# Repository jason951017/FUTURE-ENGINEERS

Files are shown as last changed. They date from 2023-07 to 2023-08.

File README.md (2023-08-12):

# 機器人比賽工程日誌 - 視覺感應避障電動車

## 簡介

歡迎來到我們的機器人比賽工程日誌！我們準備參加一場視覺感應避障電動車的比賽。我們的目標是製作一台自動導航並能根據視覺感應器來避免障礙物的電動車。這份日誌將記錄我們在組裝和優化車輛過程中的進展、挑戰和解決方案。
# 壹.移動性管理

## 一. 馬達選擇

在初期階段，我們仔細考慮了不同的馬達選項，最終選擇了更小的N20馬達，而不是EV3樂高馬達。這個選擇不僅讓我們的車輛更加緊湊，還能提供更好的靈活性，以實現有效的閃避障礙物。

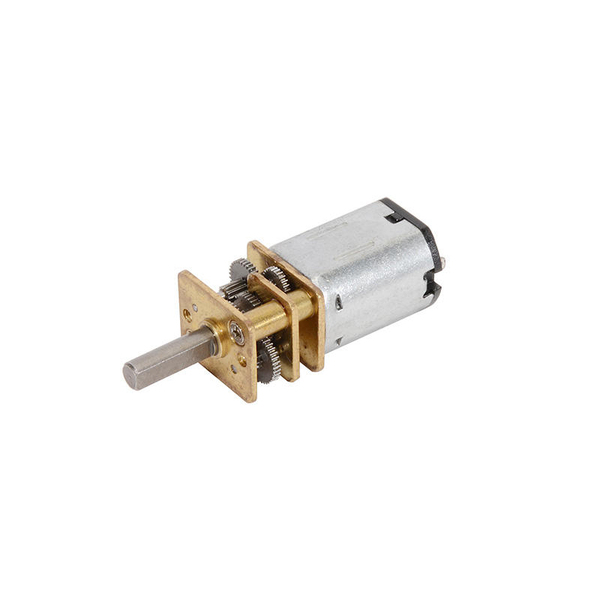
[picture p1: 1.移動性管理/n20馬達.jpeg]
N20馬達

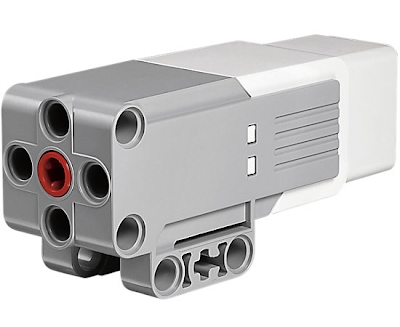
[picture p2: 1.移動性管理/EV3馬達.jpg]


## 二. 底盤設計

為了確保車輛的機動性，我們決定使用3D列印技術設計一個自定義的底盤，同時解決了遙控車底盤迴轉半徑過大的問題。這個決定將讓我們製作一個專為我們需求度身訂造的底盤，以提高整體性能。

### 遙控車迴轉半徑：

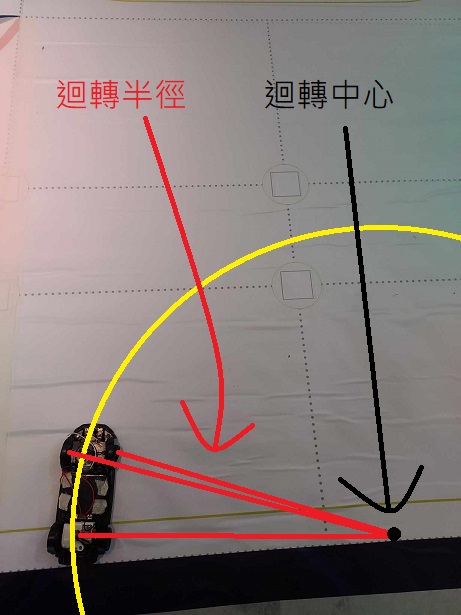
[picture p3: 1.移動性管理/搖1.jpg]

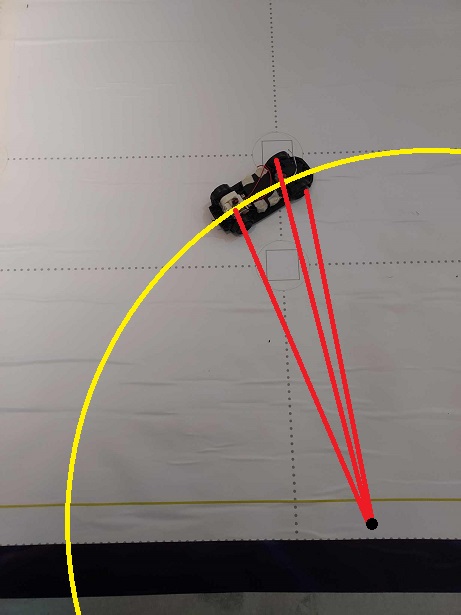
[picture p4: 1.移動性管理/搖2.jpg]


### 3D列印車迴轉半徑：

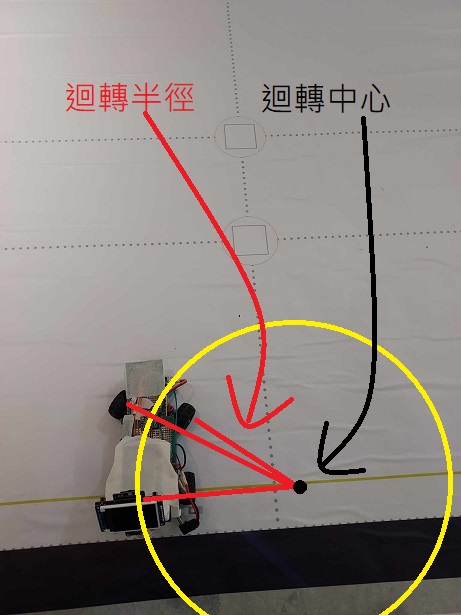
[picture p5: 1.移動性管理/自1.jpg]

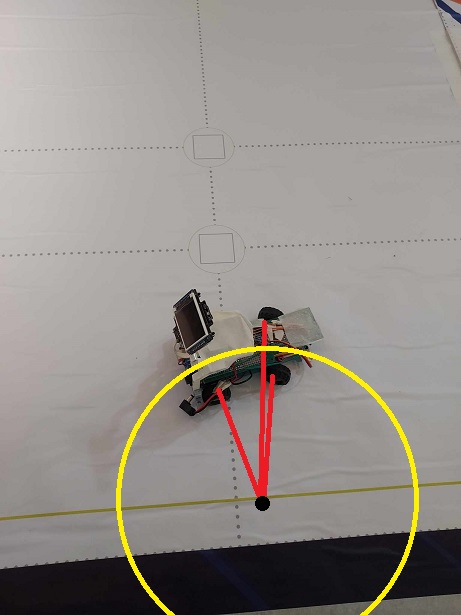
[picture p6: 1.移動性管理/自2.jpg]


由上圖比對發現遙控車底盤迴轉半徑過大，可能影響閃避交通號誌，所以最終選擇用3D列印底盤車解決此問題。

## 三. 3D列印齒輪

為了確保馬達和樂高零件的齒輪相匹配，我們自行使用3D列印技術設計了合適的齒輪。這將實現在車輛內部有效地傳遞動力。

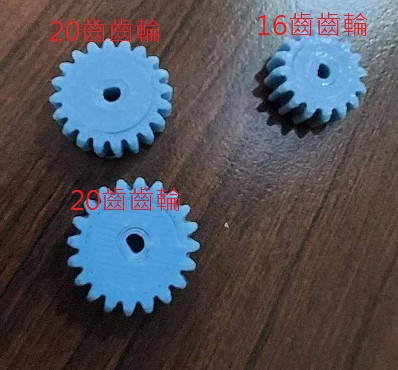
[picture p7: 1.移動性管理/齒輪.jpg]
自製齒輪


## 四. 馬達轉速

我們進行了馬達轉速的測試，以瞭解其性能特點。以下是馬達在不同電壓下的轉速結果圖：

紅色框選部分為我們挑選馬達的數據

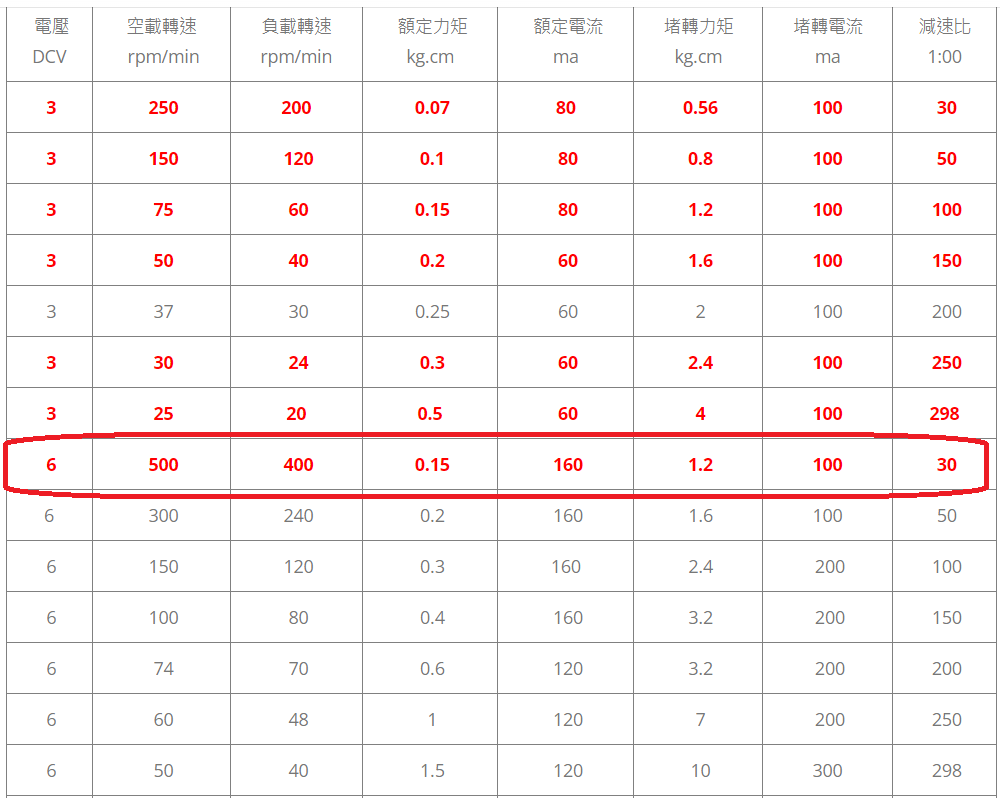
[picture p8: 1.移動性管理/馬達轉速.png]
馬達轉速圖


## 五. 差速器齒輪比

為了實現差速操控，我們計算並設計了適合後輪的差速器齒輪比大約等於400*(16-24)=266.667

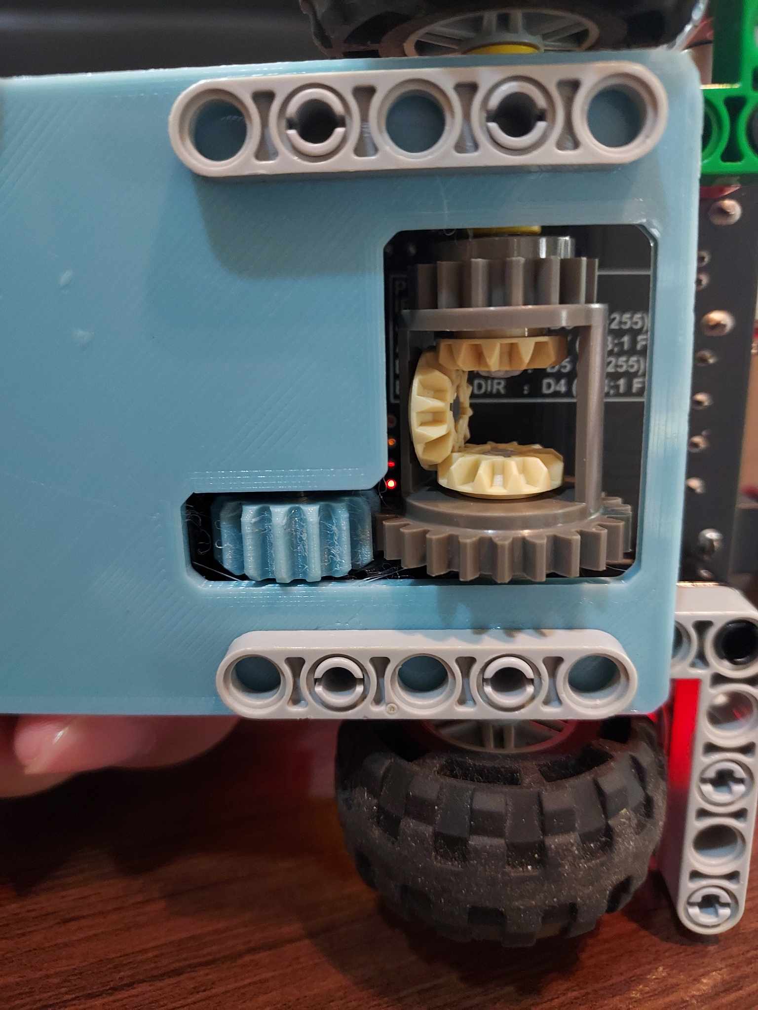
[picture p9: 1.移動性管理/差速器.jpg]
差速器齒輪


## 六. 裝配說明

以下是包括底盤和框架的裝配指南和零件實裝圖：

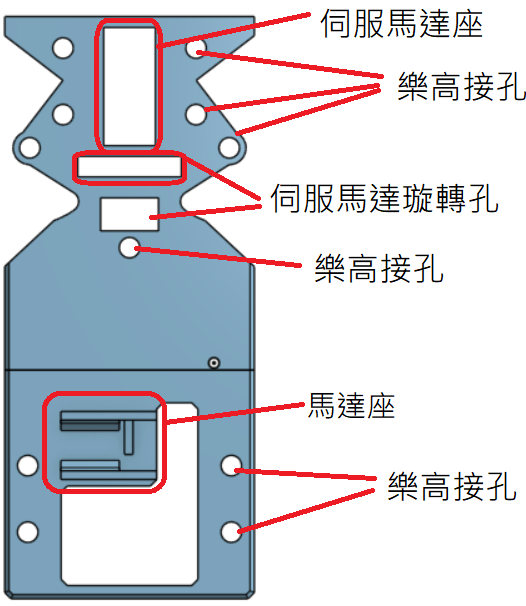
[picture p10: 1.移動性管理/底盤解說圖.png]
裝配說明

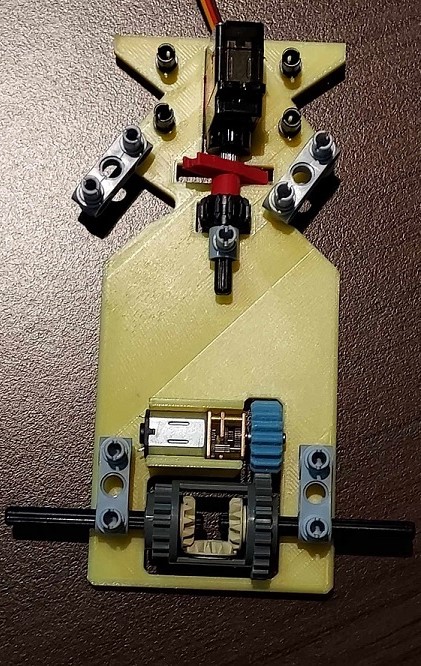
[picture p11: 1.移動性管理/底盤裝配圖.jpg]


## 七. 3D元件三視圖及stl圖檔

整個車輛元件的三視圖：

### 頂視圖：

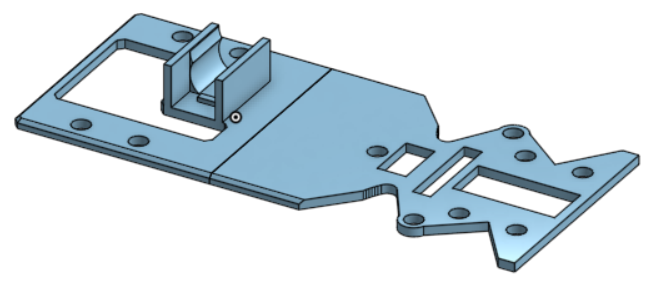
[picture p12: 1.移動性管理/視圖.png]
頂視圖


### 正視圖：

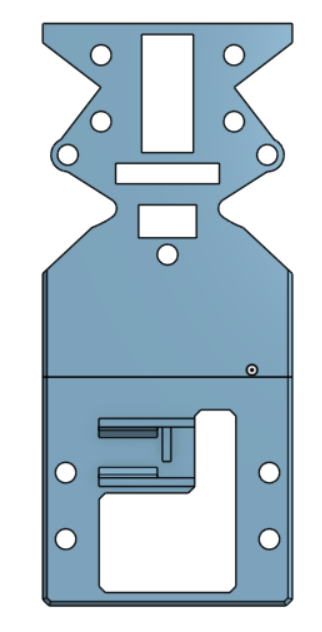
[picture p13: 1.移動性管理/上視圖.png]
正視圖


### 側視圖：

側視圖

### stl圖檔：

[stl圖檔](1.移動性管理/FE全.stl)

# 貳.電源和感測器管理

## 一. nicjoy14500金屬鋰電池

這是車輛的動力來源，提供電力給主控板、馬達以及其他電子裝置。選用金屬鋰電池而不是模型電池是因為nicjoy金屬鋰電池體積更小，更方便縮小車輛體積及配重。
一節電池電壓為3.7 ~ 4.2伏特，穩態電壓3.7伏特，我們使用兩節電池實際電壓為7.4 ~ 8.4伏特，電壓輸入到主控版後會經過穩壓晶片將電壓穩壓到5伏特和3.3伏特再分配到主控板和其他感應器。

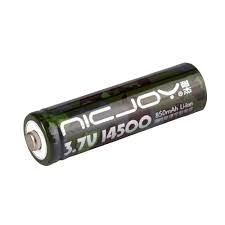
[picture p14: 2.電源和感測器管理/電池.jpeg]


## 二.主控板

Krduino主控板：這是整個車輛的主要控制板，負責管理和協調其他零件的運作。主控板通過程式碼控制各個感測器和執行器的動作，實現車輛的自主運行和障礙物避免功能。

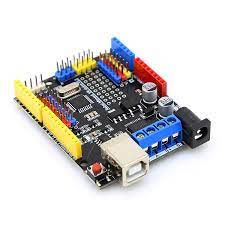
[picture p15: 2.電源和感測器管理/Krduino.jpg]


  #### 二-1 馬達驅動馬達驅動版tb6612

   tb6612是用於控制電動車的馬達。在車輛中，tb6612驅動晶片負責控制馬達的速度和方向，進而實現車輛的運動和轉向控制。已內建整合於主控板中。

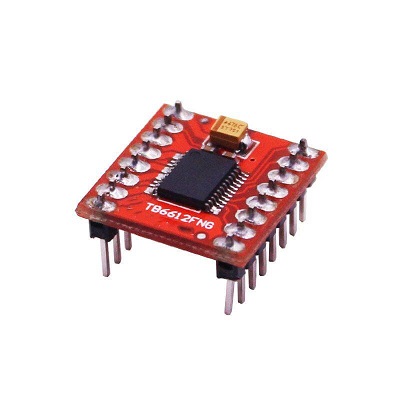
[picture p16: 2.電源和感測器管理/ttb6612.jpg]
   

## 三.陀螺儀mpu6050

這是一個慣性感測器，能夠檢測車輛的傾斜和轉動。通過i2c通訊讀取陀螺儀數據，主控板可以判斷車輛的傾斜狀態，從而實現平穩的移動和轉向。

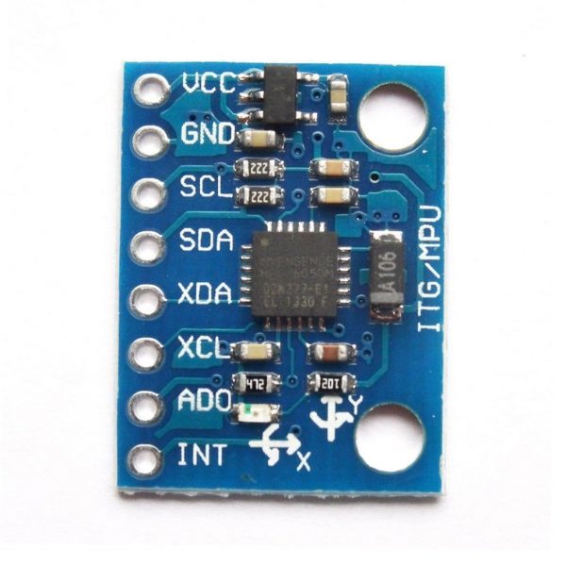
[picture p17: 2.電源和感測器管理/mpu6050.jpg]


## 四.顏色感應器tcs34725

這個感應器可以識別周圍環境的顏色。在比賽中，我們通過i2c通訊讀取感應器數據來辨別地面狀態，以便車輛做出適當的反應和閃避動作。

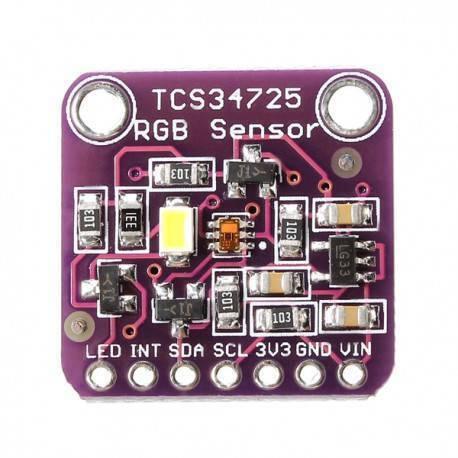
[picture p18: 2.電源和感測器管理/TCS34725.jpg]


## 五.攝影機esp32cam

攝影機是視覺感應器的一種，它可以拍攝周圍的場景。透過攝影機的影像處理，車輛可以識別前方的障礙物或路徑，並進行適應性的運動控制。

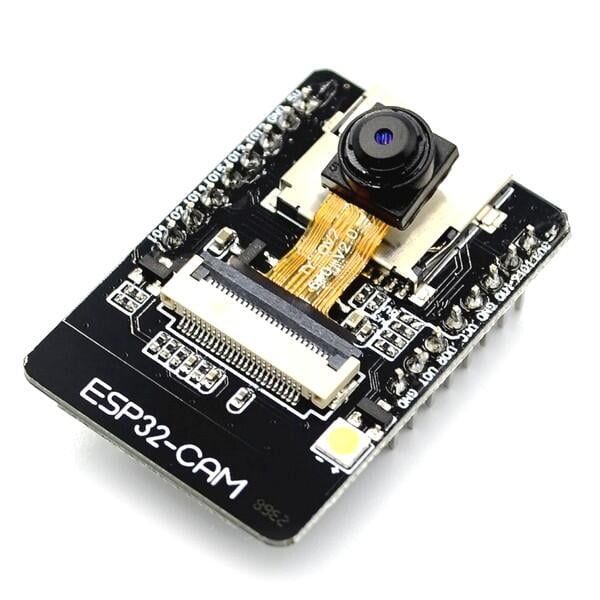
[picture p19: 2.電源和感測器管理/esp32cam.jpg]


## 六.超音波hc-sr04

這個超音波感測器可以測量車輛與前方障礙物之間的距離。藉由這個數據，車輛可以避免與障礙物碰撞，實現安全的運行。

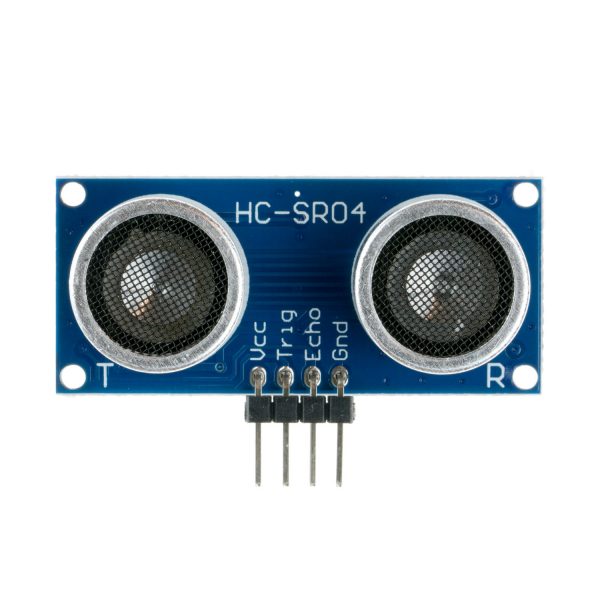
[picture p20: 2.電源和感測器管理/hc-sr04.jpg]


## 七.按鈕

按鈕是一種輸入裝置，可以用來控制車輛的啟動、停止或其他功能。在比賽中，我們將按鈕用來操控車輛的啟動。

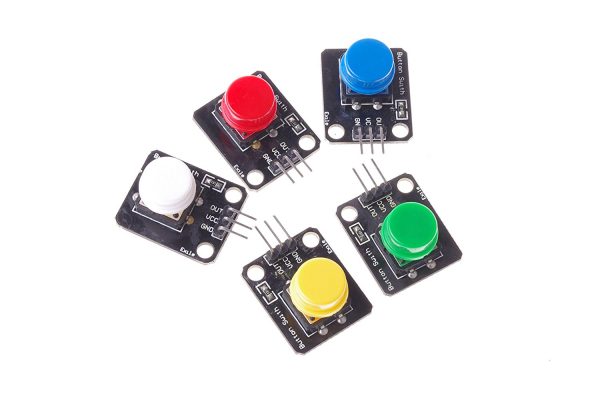
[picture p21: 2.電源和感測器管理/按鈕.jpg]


## 八.三色指示燈

這些燈光裝置用來顯示車輛的狀態或提供提示信息。例如，可以利用指示燈顯示車輛是否處於運行中，或者是否偵測到了障礙物，若程式有誤還能方便及時更正程式。



# 參.障礙管理

以下是我們車輛的程式碼

```
#include "init.h"

int ya = 0, yb = 1, cmin, cmax;

void setup() {
  // 初始化感應器
  FeInit();
  getDis();
  delayMicroseconds(250);
  static int ldis, fix5 = 0, lastColor = 0, turnback = 0;
  while (true) {
    // 沿陀螺儀相對零度角前進並進行避障
    rygSet(0, 0, 0);
    if ((CameraGet(3) > 15) || (CameraGet(7) > 15)) {
      caturn_turn();
      if (CameraGet(3) > 15) fix5 = -20;
      if (CameraGet(7) > 15) fix5 = 20;
    } else {
      setTurn(getRelGyro(0) * 1.2);
    }
    motorSpd(250);
    // 利用光源感應器分辨地面上藍橘線得知行進方向為順時針或逆時針
    int color = getTcs();
    if (color > 0 && color < 40) {
      ya = 1;
      cmin = 0;
      cmax = 40;
      break;
    }
    if (color > 200 && color < 240) {
      ya = -1;
      cmin = 200;
      cmax = 240;
      break;
    }
  }
}

// 20,220
void loop() {
  rygSet(0, 0, 0);
  static byte b = 0, c = 0;
  static int ldis, fix5 = 0, lastColor = 0;
  static uint32_t a = 0, timer = 0, back = 0, straightTime = 0;
  motorSpd(250);
  // 記數進行8次
  for (int r = 0; r < 8; r++) {
    // 前進直到偵測到地圖上藍橘線
    while (getTcs() < cmin || getTcs() > cmax) {
      // 沿陀螺儀相對零度角前進並進行避障
      if ((CameraGet(3) > 15) || (CameraGet(7) > 15)) {
        caturn_turn();
      } else {
        setTurn(getRelGyro(a + fix5) * 1.2);
      }
      if (r == 4) {
        if (CameraGet(3) > 15) {
          // 將相對角目標調整90度
          a += ya * 90;
        }
        //*****************************************************************************
        // 轉向直到與目標角度相差小於10度
        while (getRelGyro(a) > 10 || getRelGyro(a) < -10) {
          motorSpd(250);
          // 在觀測到障礙後進行避障
          if ((CameraGet(3) > 15) || (CameraGet(7) > 15)) {
            caturn_turn();
          }
          setTurn(getRelGyro(a) * 1.2);
        }
      }
    }
  }
  //*********************************************************************************************
  straightTime = millis() + 700;
  if (lastColor == -1) {
    rygSet(0, 0, 0);
    // 前進0.7秒並在途中進行避障
    while (millis() < straightTime) {
      motorSpd(250);
      caturn_turn();
    }
    //*************************************************************************************************
    // 改變地面上藍橘線目標色相值
    if (ya == 1) {
      cmin = 200;
      cmax = 240;
    } else {
      cmin = 0;
      cmax = 40;
    }
    // 沿相對角180度後退
    straightTime = millis() + 1800;
    while (millis() < straightTime) {
      motorSpd(-250);
      setTurn(getRelGyro(a) * (-1));
    }
    // 轉向直到與目標角相差小於10度
    a += ya * 90;
    while (getRelGyro(a) > 10 || getRelGyro(a) < -10) {
      motorSpd(250);
      setTurn(getRelGyro(a) * 1.2);
    }
  }
  //****************************************************************************
  // 前進1秒並在途中進行避障
  straightTime = millis() + 1000;
  while (millis() < straightTime) {
    setTurn(getRelGyro(a) * 1.2);
    caturn_turn();
  }
  //****************************************************************************
  // 記數3+(是否往反方向)次
  for (int r = 0; r < (3 + (lastColor > 0)); r++) {
    // 前進直到偵測到地圖上藍橘線
    while (getTcs() < cmin || getTcs() > cmax) {
      // 沿陀螺儀相對零度角前進並進行避障
      if ((CameraGet(3) > 15) || (CameraGet(7) > 15)) {
        caturn_turn();
      } else {
        setTurn(getRelGyro(a + fix5) * 1.2);
      }
    }
    //******************************************************************************************
    // 將目標角調整90度
    a += ya * 90 * lastColor;
    //******************************************************************************************
    // 轉向直到與目標角度相差小於10度
    while (getRelGyro(a) > 10 || getRelGyro(a) < -10) {
      motorSpd(250);
      // 在觀測到障礙後進行避障
      if ((CameraGet(3) > 15) || (CameraGet(7) > 15)) {
        caturn_turn();
      }
      setTurn(getRelGyro(a) * 1.2);
    }
  }
  //*******************************************************************************************
  // 前進0.8秒後停止
  straightTime = millis() + 800;
  while (millis() < straightTime) {
    motorSpd(250);
    caturn_turn();
  }
  while (1) {
    motorSpd(0);
  }
}

```

# 肆.圖片-團隊以及汽車

## 一.團隊照片

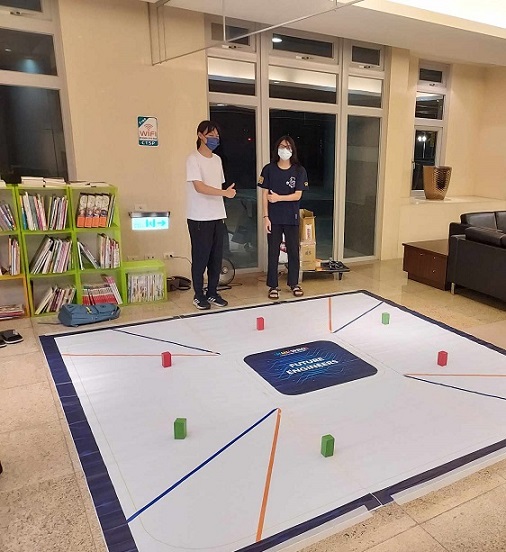
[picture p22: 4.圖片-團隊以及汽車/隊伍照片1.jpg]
隊伍照片

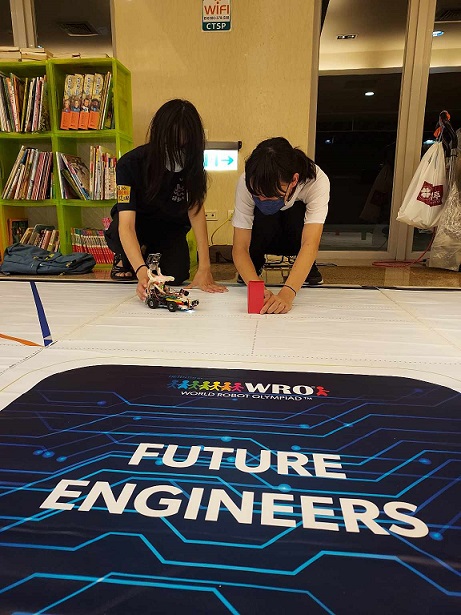
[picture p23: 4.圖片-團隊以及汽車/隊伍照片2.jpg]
隊伍照片

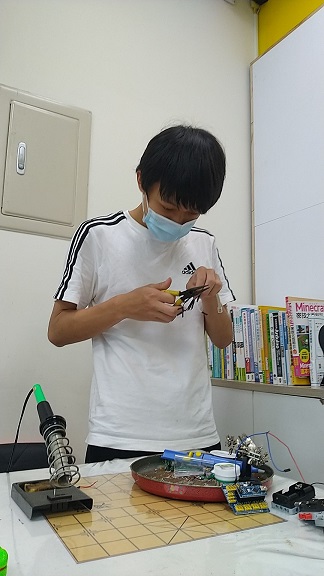
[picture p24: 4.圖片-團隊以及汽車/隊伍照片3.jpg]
隊伍照片

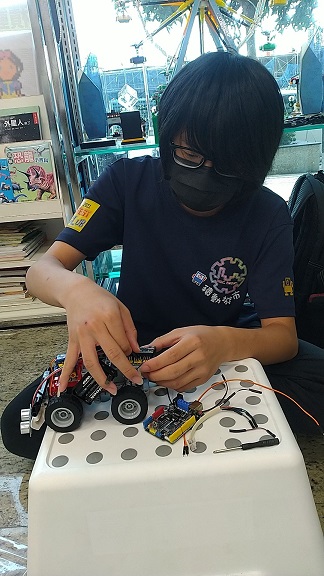
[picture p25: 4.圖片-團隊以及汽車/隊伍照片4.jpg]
隊伍照片

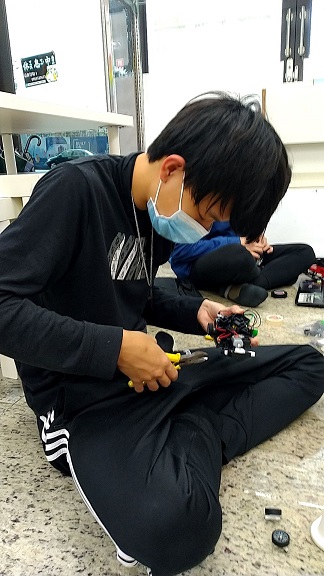
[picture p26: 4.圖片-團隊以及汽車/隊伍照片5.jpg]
隊伍照片

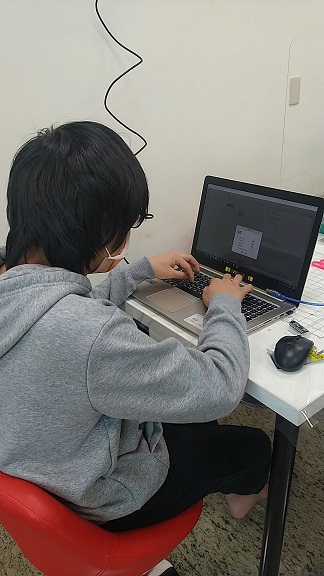
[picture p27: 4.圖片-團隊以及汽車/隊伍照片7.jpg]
隊伍照片

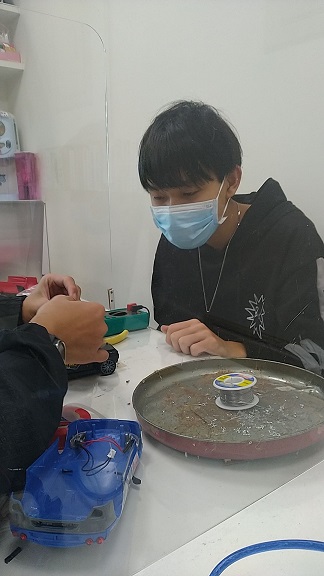
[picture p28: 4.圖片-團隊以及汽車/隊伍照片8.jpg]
隊伍照片

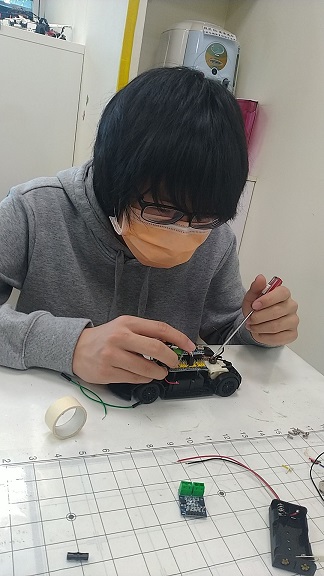
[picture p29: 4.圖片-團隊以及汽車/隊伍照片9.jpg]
隊伍照片

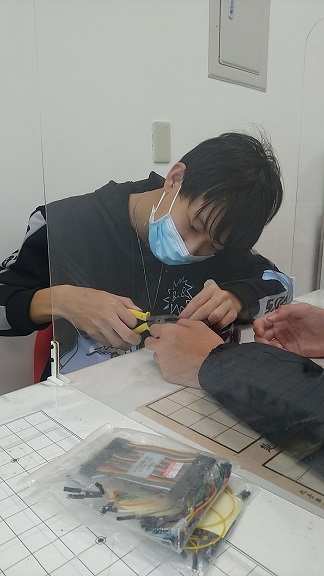
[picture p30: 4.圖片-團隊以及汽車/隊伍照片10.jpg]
隊伍照片

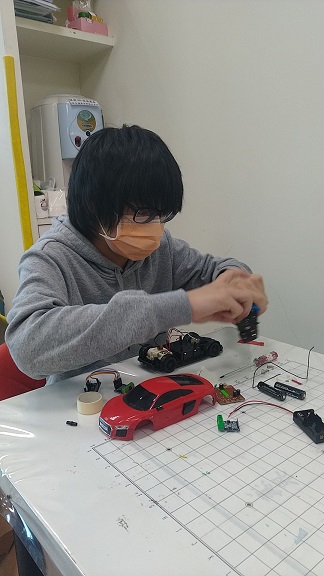
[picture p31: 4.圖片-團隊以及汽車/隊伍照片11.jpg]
隊伍照片

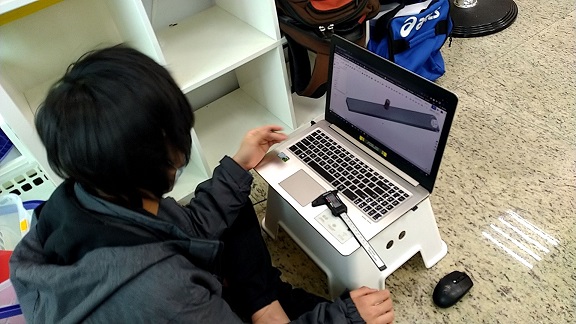
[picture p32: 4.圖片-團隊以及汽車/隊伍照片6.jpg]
隊伍照片


## 二.車輛照片

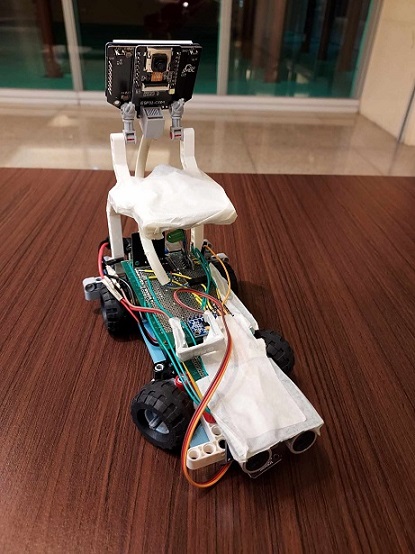
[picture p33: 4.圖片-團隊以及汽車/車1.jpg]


## 側視圖:

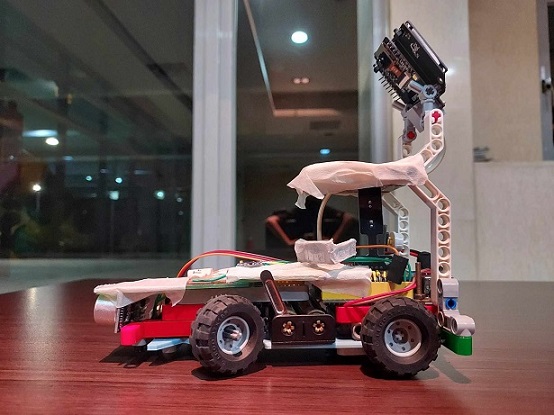
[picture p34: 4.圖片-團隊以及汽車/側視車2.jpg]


## 上視圖:

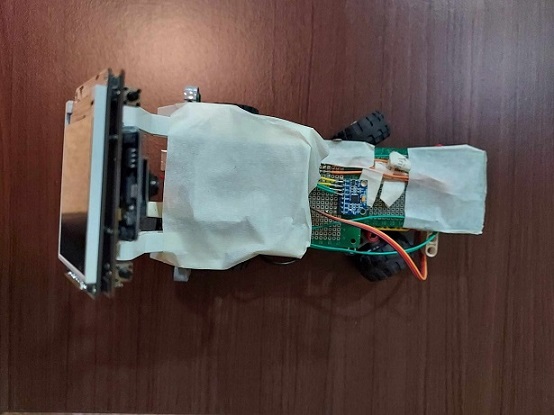
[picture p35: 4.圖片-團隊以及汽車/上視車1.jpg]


# 伍.完整的影片

## 影片連結:

### future engineer-開放挑戰
https://www.youtube.com/watch?v=iF_I76seYgM

### 障礙物挑戰-有迴轉
https://www.youtube.com/watch?v=U3aca9URPHw

### 障礙物挑戰-無迴轉
https://www.youtube.com/watch?v=v_WyIpfcISQ

# 陸.GitHub使用

## GitHub使用心得
我是一個幾乎不會打報告、上網查資料的人，但這次參加Future Engineer比賽之後，我開始使用GitHub來紀錄我的比賽實驗過程。這是一個讓我難以置信的改變，讓我在技術和協作方面得到了巨大的成長。一開始，我對於GitHub毫無了解，但是在比賽中，我不得不學會如何使用它，因為它是我們整個比賽的過程記錄中心。這次Future Engineer比賽讓我成為了一個會使用GitHub、上網查資料的人。GitHub幫助我更好地組織我的工作、與團隊合作、學習他人的經驗，並且使我對於技術更加自信。我相信這個工具將會伴隨著我在未來的學習和職業生涯中，繼續扮演著重要的角色。

# 柒.工程因素及技術條件
這一個章節要呈現我們自行設計和製造車輛和部件，以及整合現成的電子零件。

## 一.現成電子零件

### 1.nicjoy14500金屬鋰電池

這是車輛的動力來源，提供電力給主控板、馬達以及其他電子裝置。選用金屬鋰電池而不是模型電池是因為nicjoy金屬鋰電池體積更小，更方便縮小車輛體積及配重。
一節電池電壓為3.7 ~ 4.2伏特，穩態電壓3.7伏特，我們使用兩節電池實際電壓為7.4 ~ 8.4伏特，電壓輸入到主控版後會經過穩壓晶片將電壓穩壓到5伏特和3.3伏特再分配到主控板和其他感應器。



### 2.主控板

Krduino主控板：這是整個車輛的主要控制板，負責管理和協調其他零件的運作。主控板通過程式碼控制各個感測器和執行器的動作，實現車輛的自主運行和障礙物避免功能。



   2-1 馬達驅動馬達驅動版tb6612

   tb6612是用於控制電動車的馬達。在車輛中，tb6612驅動晶片負責控制馬達的速度和方向，進而實現車輛的運動和轉向控制。已內建整合於主控板中。

   

### 2.陀螺儀mpu6050

這是一個慣性感測器，能夠檢測車輛的傾斜和轉動。通過i2c通訊讀取陀螺儀數據，主控板可以判斷車輛的傾斜狀態，從而實現平穩的移動和轉向。



### 3.顏色感應器tcs34725

這個感應器可以識別周圍環境的顏色。在比賽中，我們通過i2c通訊讀取感應器數據來辨別地面狀態，以便車輛做出適當的反應和閃避動作。



### 4.攝影機esp32cam

攝影機是視覺感應器的一種，它可以拍攝周圍的場景。透過攝影機的影像處理，車輛可以識別前方的障礙物或路徑，並進行適應性的運動控制。



### 5.超音波hc-sr04

這個超音波感測器可以測量車輛與前方障礙物之間的距離。藉由這個數據，車輛可以避免與障礙物碰撞，實現安全的運行。



### 6.按鈕

按鈕是一種輸入裝置，可以用來控制車輛的啟動、停止或其他功能。在比賽中，我們將按鈕用來操控車輛的啟動。



### 7.三色指示燈

這些燈光裝置用來顯示車輛的狀態或提供提示信息。例如，可以利用指示燈顯示車輛是否處於運行中，或者是否偵測到了障礙物，若程式有誤還能方便及時更正程式。



## 二. 介紹初代汽車和改進後的車輛

### 1.初代汽車照片
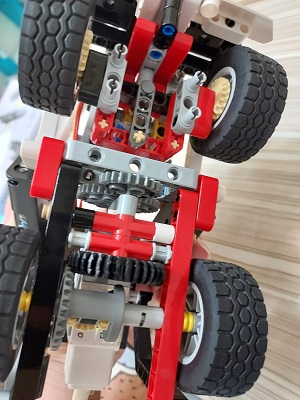
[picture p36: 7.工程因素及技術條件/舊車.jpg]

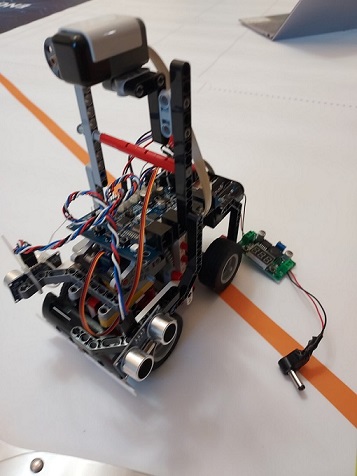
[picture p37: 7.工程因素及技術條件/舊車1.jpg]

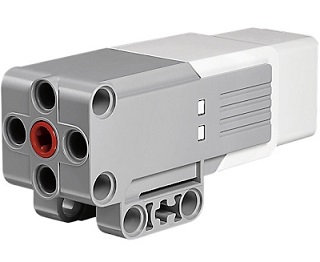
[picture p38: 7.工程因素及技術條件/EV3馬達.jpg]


這是改裝前的初代汽車底盤照片，使用的是EV3馬達，整輛車幾乎都是用樂高零件組成，看起來是一輛體積相對稍大的車輛。

### 2.改進後的車輛


這是改進後的車輛照片，我們改裝了底盤和馬達，加入了新的零件和設備，使車輛體積縮小的同時擁有了更多功能。

## 三. 焊接電路板和電路板功能
我們加裝這塊電路板是因為之前沒電路板的機構容易因使用時常增加，導致杜邦線鬆，動進而引發接觸不良的問題，所以自己到電子材料行買了兩塊焊接板自己製作一塊電路板。

### 1.電路板接線設計圖
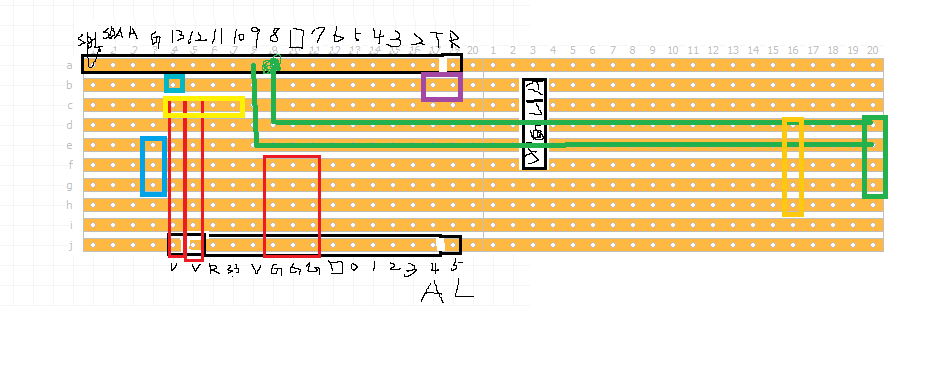
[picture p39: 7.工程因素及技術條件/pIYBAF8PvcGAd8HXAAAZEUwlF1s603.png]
電路板接線設計圖


這是我們為電路板進行的接線設計圖，確保電路板的連接正確，以實現各個零件間的順利通訊。

### 2.電路板焊接過程
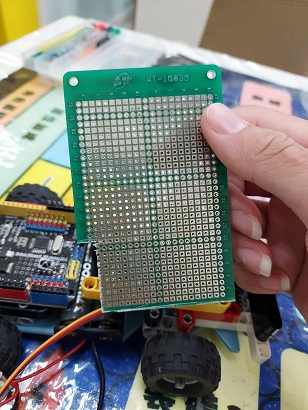
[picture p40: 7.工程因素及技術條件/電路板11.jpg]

電路板
電路板

這是電路板焊接過程的照片，我們仔細地將各個電子元件焊接在電路板上，確保連接可靠且無誤。

### 3.電路板完成圖
電路板完成圖
電路板完成圖

### 4.電路板突發狀況

由於鄰近比賽，車輛上的krduino主控板晶片因操作不當導致短路燒壞控板，所以主控板臨時改成arduino UNO板。

由於krduino板和UNO板有一些腳位差異，所以將電路板的一些接角重新焊接。
出事

這是已完成且裝配好的電路板照片，所有電子元件都已經焊接完成並接線正確。這個電路板是整個車輛的核心，它負責接收和處理各個感測器的數據，並控制馬達和其他執行器的動作，以實現車輛的自主運行和視覺感應閃避障礙物功能。
## 四. 底盤設計

為了確保車輛的機動性，我們決定使用3D列印技術設計一個自定義的底盤，同時解決了遙控車底盤迴轉半徑過大的問題。這個決定將讓我們製作一個專為我們需求度身訂造的底盤，以提高整體性能。

### 1. 遙控車迴轉半徑：

遙控車
遙控車

### 3D列印車迴轉半徑：

3D車
3D車

由上圖比對發現遙控車底盤迴轉半徑過大，可能影響閃避交通號誌，所以最終選擇用3D列印底盤車解決此問題。

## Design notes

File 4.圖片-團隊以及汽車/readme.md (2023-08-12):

## 1.團隊照片

隊伍照片
隊伍照片
隊伍照片
隊伍照片
隊伍照片
隊伍照片
隊伍照片
隊伍照片
隊伍照片
隊伍照片
隊伍照片

## 2.車輛照片



# 側視圖:



# 上視圖:



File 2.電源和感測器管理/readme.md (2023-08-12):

## 一. nicjoy14500金屬鋰電池

這是車輛的動力來源，提供電力給主控板、馬達以及其他電子裝置。選用金屬鋰電池而不是模型電池是因為nicjoy金屬鋰電池體積更小，更方便縮小車輛體積及配重。
一節電池電壓為3.7 ~ 4.2伏特，穩態電壓3.7伏特，我們使用兩節電池實際電壓為7.4 ~ 8.4伏特，電壓輸入到主控版後會經過穩壓晶片將電壓穩壓到5伏特和3.3伏特再分配到主控板和其他感應器。



## 二.主控板

Krduino主控板：這是整個車輛的主要控制板，負責管理和協調其他零件的運作。主控板通過程式碼控制各個感測器和執行器的動作，實現車輛的自主運行和障礙物避免功能。



   二-1 馬達驅動馬達驅動版tb6612

   tb6612是用於控制電動車的馬達。在車輛中，tb6612驅動晶片負責控制馬達的速度和方向，進而實現車輛的運動和轉向控制。已內建整合於主控板中。

   

## 三.陀螺儀mpu6050

這是一個慣性感測器，能夠檢測車輛的傾斜和轉動。通過i2c通訊讀取陀螺儀數據，主控板可以判斷車輛的傾斜狀態，從而實現平穩的移動和轉向。



## 四.顏色感應器tcs34725

這個感應器可以識別周圍環境的顏色。在比賽中，我們通過i2c通訊讀取感應器數據來辨別地面狀態，以便車輛做出適當的反應和閃避動作。



## 五.攝影機esp32cam

攝影機是視覺感應器的一種，它可以拍攝周圍的場景。透過攝影機的影像處理，車輛可以識別前方的障礙物或路徑，並進行適應性的運動控制。



## 六.超音波hc-sr04

這個超音波感測器可以測量車輛與前方障礙物之間的距離。藉由這個數據，車輛可以避免與障礙物碰撞，實現安全的運行。



## 七.按鈕

按鈕是一種輸入裝置，可以用來控制車輛的啟動、停止或其他功能。在比賽中，我們將按鈕用來操控車輛的啟動。



## 八.三色指示燈

這些燈光裝置用來顯示車輛的狀態或提供提示信息。例如，可以利用指示燈顯示車輛是否處於運行中，或者是否偵測到了障礙物，若程式有誤還能方便及時更正程式。



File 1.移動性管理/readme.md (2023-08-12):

# 機器人比賽工程日誌 - 視覺感應避障電動車

## 簡介

歡迎來到我們的機器人比賽工程日誌！我們準備參加一場視覺感應避障電動車的比賽。我們的目標是製作一台自動導航並能根據視覺感應器來避免障礙物的電動車。這份日誌將記錄我們在組裝和優化車輛過程中的進展、挑戰和解決方案。

## 一. 馬達選擇

在初期階段，我們仔細考慮了不同的馬達選項，最終選擇了更小的N20馬達，而不是EV3樂高馬達。這個選擇不僅讓我們的車輛更加緊湊，還能提供更好的靈活性，以實現有效的閃避障礙物。

N20馬達
EV3馬達

## 二. 底盤設計

為了確保車輛的機動性，我們決定使用3D列印技術設計一個自定義的底盤，同時解決了遙控車底盤迴轉半徑過大的問題。這個決定將讓我們製作一個專為我們需求度身訂造的底盤，以提高整體性能。

### 遙控車迴轉半徑：

遙控車
遙控車

### 3D列印車迴轉半徑：

3D車
3D車

由上圖比對發現遙控車底盤迴轉半徑過大，可能影響閃避交通號誌，所以最終選擇用3D列印底盤車解決此問題。

## 三. 3D列印齒輪

為了確保馬達和樂高零件的齒輪相匹配，我們自行使用3D列印技術設計了合適的齒輪。這將實現在車輛內部有效地傳遞動力。

自製齒輪

## 四. 馬達轉速

我們進行了馬達轉速的測試，以瞭解其性能特點。以下是馬達在不同電壓下的轉速結果圖：

紅色框選部分為我們挑選馬達的數據

馬達轉速圖

## 五. 差速器齒輪比

為了實現差速操控，我們計算並設計了適合後輪的差速器齒輪比大約等於400*(16-24)=266.667

差速器齒輪

## 六. 裝配說明

以下是包括底盤和框架的裝配指南和零件實裝圖：

裝配說明


## 七. 3D元件三視圖及stl圖檔

整個車輛元件的三視圖：

### 頂視圖：

頂視圖

### 正視圖：

正視圖

### 側視圖：

側視圖

### stl圖檔：

[stl圖檔](FE全.stl)

## 總結

作為準備參加機器人比賽的參賽選手，我們致力於從理論到實踐，不斷優化我們的電動車項目。在視覺感應避障電動車的構建過程中，我們將著重於馬達、齒輪、感應器和差速器的組裝與優化。這個日誌將是我們工程進度的詳盡紀錄，同時也會反映出我們團隊的合作精神和創新思維。讓我們攜手合作，打造一輛優秀的視覺感應避障電動車。

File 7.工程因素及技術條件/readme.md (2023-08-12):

# 柒.工程因素及技術條件
這一個章節要呈現我們自行設計和製造車輛和部件，以及整合現成的電子零件。

## 一.現成電子零件

1.nicjoy14500金屬鋰電池

這是車輛的動力來源，提供電力給主控板、馬達以及其他電子裝置。選用金屬鋰電池而不是模型電池是因為nicjoy金屬鋰電池體積更小，更方便縮小車輛體積及配重。
一節電池電壓為3.7 ~ 4.2伏特，穩態電壓3.7伏特，我們使用兩節電池實際電壓為7.4 ~ 8.4伏特，電壓輸入到主控版後會經過穩壓晶片將電壓穩壓到5伏特和3.3伏特再分配到主控板和其他感應器。



2.主控板

Krduino主控板：這是整個車輛的主要控制板，負責管理和協調其他零件的運作。主控板通過程式碼控制各個感測器和執行器的動作，實現車輛的自主運行和障礙物避免功能。



   2-1 馬達驅動馬達驅動版tb6612

   tb6612是用於控制電動車的馬達。在車輛中，tb6612驅動晶片負責控制馬達的速度和方向，進而實現車輛的運動和轉向控制。已內建整合於主控板中。

   

2.陀螺儀mpu6050

這是一個慣性感測器，能夠檢測車輛的傾斜和轉動。通過i2c通訊讀取陀螺儀數據，主控板可以判斷車輛的傾斜狀態，從而實現平穩的移動和轉向。



3.顏色感應器tcs34725

這個感應器可以識別周圍環境的顏色。在比賽中，我們通過i2c通訊讀取感應器數據來辨別地面狀態，以便車輛做出適當的反應和閃避動作。



4.攝影機esp32cam

攝影機是視覺感應器的一種，它可以拍攝周圍的場景。透過攝影機的影像處理，車輛可以識別前方的障礙物或路徑，並進行適應性的運動控制。



5.超音波hc-sr04

這個超音波感測器可以測量車輛與前方障礙物之間的距離。藉由這個數據，車輛可以避免與障礙物碰撞，實現安全的運行。



6.按鈕

按鈕是一種輸入裝置，可以用來控制車輛的啟動、停止或其他功能。在比賽中，我們將按鈕用來操控車輛的啟動。



7.三色指示燈

這些燈光裝置用來顯示車輛的狀態或提供提示信息。例如，可以利用指示燈顯示車輛是否處於運行中，或者是否偵測到了障礙物，若程式有誤還能方便及時更正程式。



## 二. 介紹初代汽車和改進後的車輛

### 1.初代汽車照片
舊車
舊車
EV3馬達

這是改裝前的初代汽車底盤照片，使用的是EV3馬達，整輛車幾乎都是用樂高零件組成，看起來是一輛體積相對稍大的車輛。

### 2.改進後的車輛


這是改進後的車輛照片，我們改裝了底盤和馬達，加入了新的零件和設備，使車輛體積縮小的同時擁有了更多功能。

## 三. 焊接電路板和電路板功能
我們加裝這塊電路板是因為之前沒電路板的機構容易因使用時常增加，導致杜邦線鬆，動進而引發接觸不良的問題，所以自己到電子材料行買了兩塊焊接板自己製作一塊電路板。

### 1.電路板接線設計圖
電路板接線設計圖

這是我們為電路板進行的接線設計圖，確保電路板的連接正確，以實現各個零件間的順利通訊。

### 2.電路板焊接過程
電路板
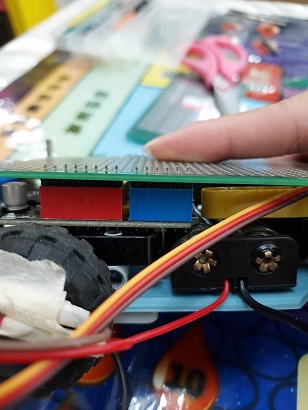
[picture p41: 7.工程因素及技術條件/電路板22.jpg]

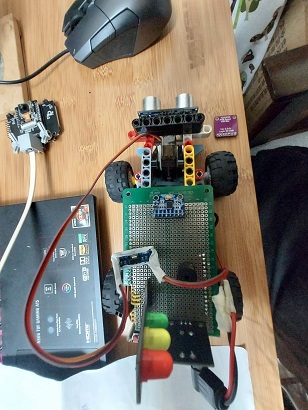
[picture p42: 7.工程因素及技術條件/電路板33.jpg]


這是電路板焊接過程的照片，我們仔細地將各個電子元件焊接在電路板上，確保連接可靠且無誤。

### 3.電路板完成圖
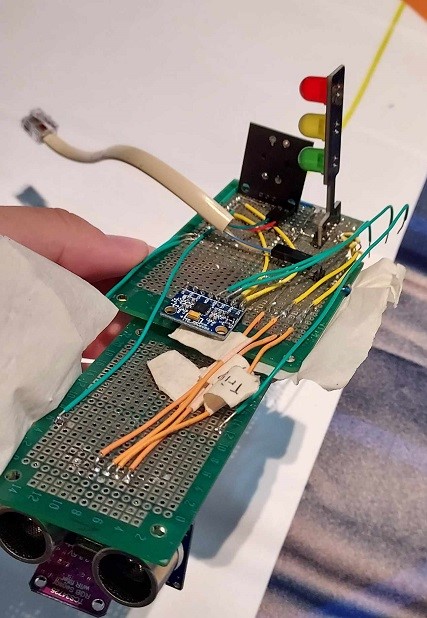
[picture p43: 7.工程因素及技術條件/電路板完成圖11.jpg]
電路板完成圖

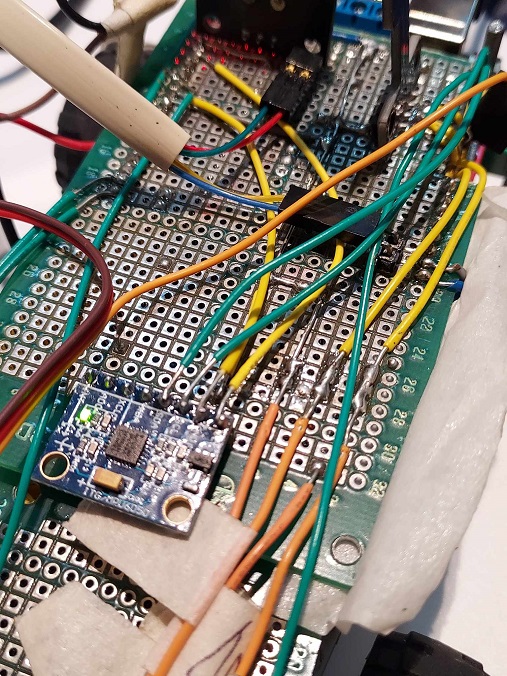
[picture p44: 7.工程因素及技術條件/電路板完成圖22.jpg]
電路板完成圖


### 4.電路板突發狀況

由於鄰近比賽，車輛上的krduino主控板晶片因操作不當導致短路燒壞控板，所以主控板臨時改成arduino UNO板。

由於krduino板和UNO板有一些腳位差異，所以將電路板的一些接角重新焊接。
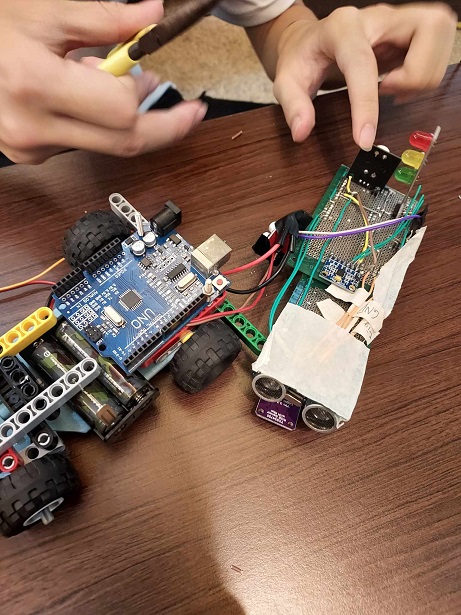
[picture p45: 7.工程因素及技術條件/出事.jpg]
出事


這是已完成且裝配好的電路板照片，所有電子元件都已經焊接完成並接線正確。這個電路板是整個車輛的核心，它負責接收和處理各個感測器的數據，並控制馬達和其他執行器的動作，以實現車輛的自主運行和視覺感應閃避障礙物功能。
## 四. 底盤設計

為了確保車輛的機動性，我們決定使用3D列印技術設計一個自定義的底盤，同時解決了遙控車底盤迴轉半徑過大的問題。這個決定將讓我們製作一個專為我們需求度身訂造的底盤，以提高整體性能。

### 1. 遙控車迴轉半徑：

遙控車
遙控車

### 3D列印車迴轉半徑：

3D車
3D車

由上圖比對發現遙控車底盤迴轉半徑過大，可能影響閃避交通號誌，所以最終選擇用3D列印底盤車解決此問題。

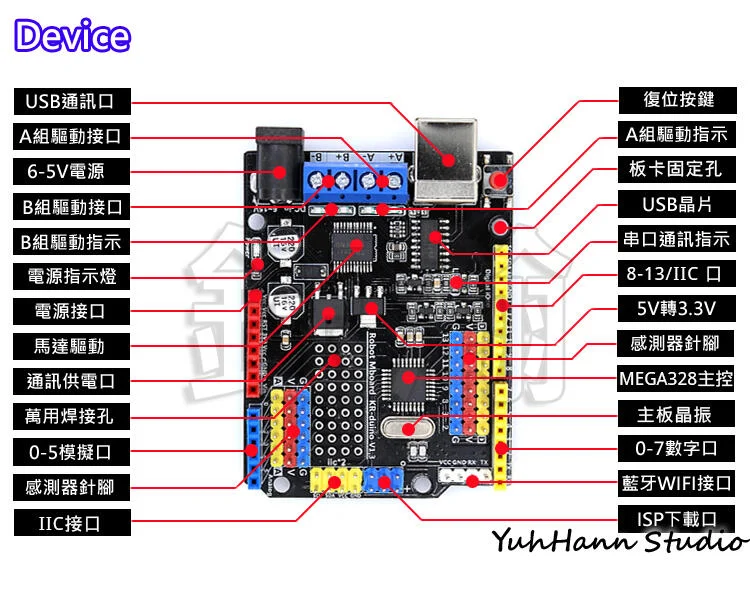
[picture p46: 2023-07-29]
7.工程因素及技術條件/Krduino主板結構.webp

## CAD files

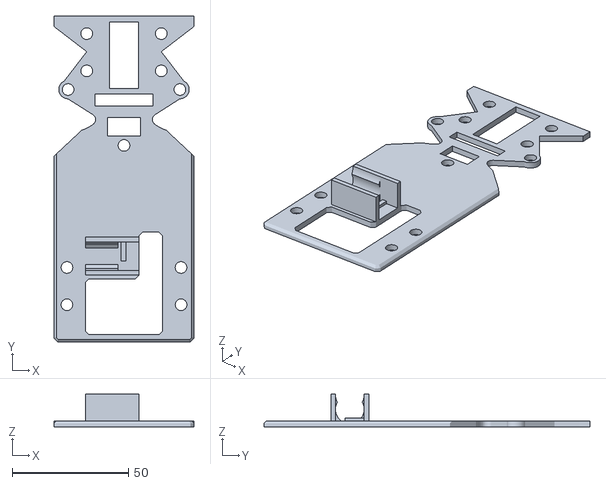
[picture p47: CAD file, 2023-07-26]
1.移動性管理/FE全.stl
60.0 x 140.0 x 14.0
